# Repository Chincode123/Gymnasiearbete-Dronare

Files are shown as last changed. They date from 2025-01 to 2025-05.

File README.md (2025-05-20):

# Remote Controlled Drone

This repository contains the software part of a multi-person project with the goal of creating a remote-controlled drone using Arduino microcontrollers, basic, consumer components, and 3D printers.

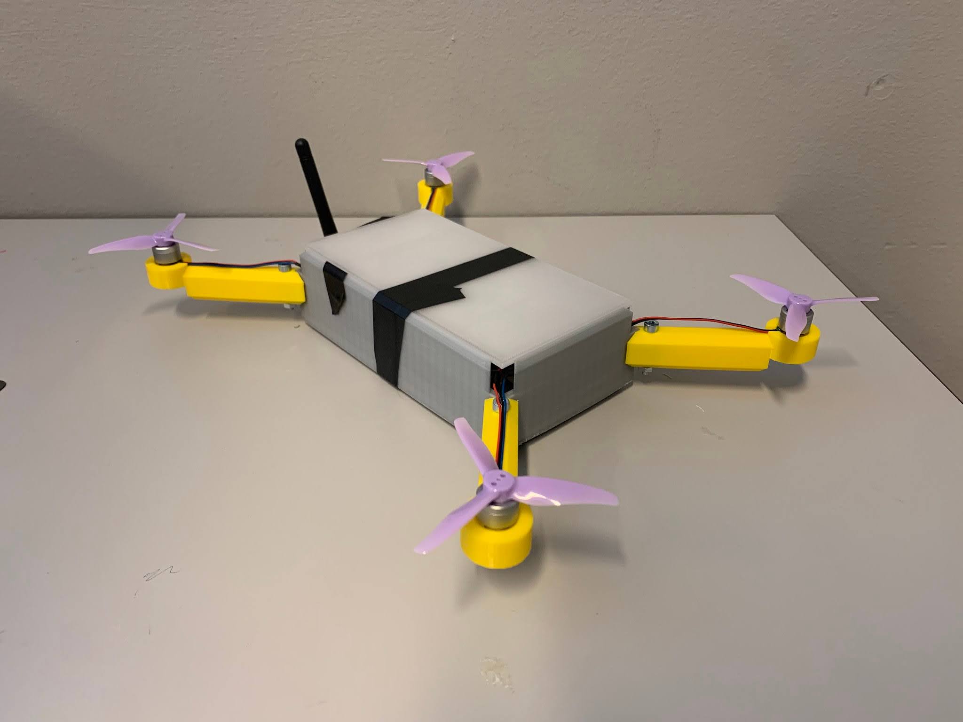
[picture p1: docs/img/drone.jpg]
Drone


## Table of Contents

- [Remote Controlled Drone](#remote-controlled-drone)
  - [Table of Contents](#table-of-contents)
  - [Project Abstract](#project-abstract)
  - [Materials](#materials)
  - [Drone](#drone)
    - [Basic Structure](#basic-structure)
      - [Setup](#setup)
      - [Main Loop](#main-loop)
        - [Radio Input](#radio-input)
        - [Flight Control](#flight-control)
        - [Radio Output](#radio-output)
      - [Important Helper Functions](#important-helper-functions)
        - [`setDeltaTime`](#setdeltatime)
        - [`sendRadio`](#sendradio)
        - [Activation and Deactivation Functions](#activation-and-deactivation-functions)
    - [Important Classes](#important-classes)
      - [`PID`](#pid)
      - [`MotorController`](#motorcontroller)
      - [`Orientation`](#orientation)
      - [`RadioSendStack`](#radiosendstack)
      - [`Timer` (drone)](#timer-drone)
      - [`vector3<T>`](#vector3t)
        - [Other](#other)
    - [Summary of Drone](#summary-of-drone)
  - [Receiver](#receiver)
    - [Basic Structure](#basic-structure-1)
      - [Setup](#setup-1)
      - [Main Loop](#main-loop-1)
        - [Serial Input](#serial-input)
        - [Radio Input](#radio-input-1)
    - [Important Classes](#important-classes-1)
      - [`InstructionHandler`](#instructionhandler)
      - [`Timer` (receiver)](#timer-receiver)
    - [Summary of Receiver](#summary-of-receiver)
  - [Control Panel](#control-panel)
    - [Basic Structure](#basic-structure-2)
      - [Setup](#setup-2)
      - [Main Loop](#main-loop-2)
        - [User Input](#user-input)
        - [Serial Communication](#serial-communication)
        - [Connection Status Indicators](#connection-status-indicators)
        - [Data Collection](#data-collection)
    - [Important Classes](#important-classes-2)
      - [`SerialMessage`](#serialmessage)
      - [`SerialReader`](#serialreader)
      - [`Terminal`](#terminal)
      - [`WritingHandler`](#writinghandler)
    - [Summary of Control Panel](#summary-of-control-panel)
  - [Simulation](#simulation)
    - [Features](#features)
    - [How to Use](#how-to-use)
    - [Notes](#notes)
    - [Summary of Simulation](#summary-of-simulation)
  - [Summary](#summary)

## Project-Abstract

The objective of this project was to explore the feasibility of designing and building a simple, radio-controlled drone using a 3D printer and an Arduino microcontroller. As the use of unmanned aerial vehicles (UAVs) becomes increasingly common in both civilian and military contexts, this project aimed to investigate how accessible such technology is for amateur hobbyists or small-scale operations. The drone was designed with a modular 3D-printed frame consisting of six parts: a central body, four arms, and a lid. The design process went through three major iterations, improving aspects such as size, weight, and internal component layout. The final version was longer and wider to better accommodate the electronic systems. The software was split into four modules: one for overall drone control, one for the radio receiver, a web-based interface for remote operation, and a Unity simulation to calibrate motor behavior using a PID controller. The finished drone had a total weight of approximately 453 grams and maintained wireless signal communication up to 290 meters, exceeding the 250-meter requirement. However, due to hardware limitations, flight testing was incomplete, and the drone's flight time could not be verified. Based on motor specifications, it is unlikely that the drone would meet the targeted 10-minute flight duration. Despite these limitations, the project successfully demonstrated the development of a modular frame, functional software integration, and RF24-based wireless communication. Future improvements should focus on optimizing aerodynamic design, enhancing sensor feedback integration, and developing efficient battery management. Overall, the project provides a strong foundation for future iterations and highlights both the possibilities and challenges of constructing UAVs with limited resources.

## Materials

- 4 DarwinFPV 1104 motors
- 4 Gemfan 3016 propellers
- 2 Ebyte E01-ML01DP5 radio tranceivers
- 1 MPU 6050 gyroscope/accelerometer
- 1 Capacitor
- 1 7.4 Volt 3000 mAh LiPo 2S battery
- 1 3.7 Volt 300 mAh LiPo 1S battery
- 1 Jhemcu EM-40A 4 in 1 ESC
- 1 Arduino MKR Zero
- 1 Arduino Uno
- 3D-printer + filament
- Soldering and wire handling equipment

## Drone

[`Drone.ino`](Drone/Drone.ino) is intended to be used with an `Arduino MKR Zero` alongside an [`MPU 6050`](https://www.invensense.com/products/motion-tracking/6-axis/mpu-6050/) gyroscope/accelerometer, an [`nRF24L01`](https://github.com/nRF24/RF24) radio device, and a set of `DarwinFPV 1104` brushless motors.

> **_NOTE:_** It will likely work with other components, with some minor modifications to the code.

### Basic Structure

[`Drone.ino`](Drone/Drone.ino) is the sketch file for the drone and, by using both public `Arduino` libraries and the custom-made [`DroneLibrary`](DroneLibrary), it handles the control flow for the drone.

> **_NOTE:_** To use `DroneLibrary` with the Arduino IDE, copy the `DroneLibrary` folder into your `Arduino/libraries` directory.

#### Setup

As with most `Arduino` sketches, the [`Drone.ino`](Drone/Drone.ino) file includes a setup function.

```cpp
void setup() {
    ...

    while (!radio.begin()) { }
    while (!configureRadio(radio)) { }
    radio.openWritingPipe(DRONE_ADDRESS);
    radio.openReadingPipe(1, RECEIVER_ADDRESS);
    radio.startListening();

    motorController.setTargetValues(&targetVelocity, &targetPitch, &targetRoll);
    motorController.setVelocityConstants(PID_Velocity);
    motorController.setPitchConstants(PID_Pitch);
    motorController.setRollConstants(PID_Roll);

    motorTL.attach(MOTOR_TL_Pin, 1000, 2000);
    motorTR.attach(MOTOR_TR_Pin, 1000, 2000);
    motorBR.attach(MOTOR_BR_Pin, 1000, 2000);
    motorBL.attach(MOTOR_BL_Pin, 1000, 2000);

    motorTL.writeMicroseconds(1000);
    motorTR.writeMicroseconds(1000);
    motorBR.writeMicroseconds(1000);
    motorBL.writeMicroseconds(1000);

    previousTime = micros();

    radioLogPush("Connected");

    ...
}
```

Firstly, the radio transceiver is configured:
- `radio.begin()` initializes the radio transceiver.
- `configureRadio(radio)` configures the transceiver's settings.
- Writing and reading pipes are opened with addresses defined in [`RadioData.h`](DroneLibrary/RadioData.h).
- `radio.startListening()` enables the transceiver to listen for instructions.

Secondly, the motor controller and motors are configured:
- The `MotorController` is set up with target values and PID constants.
- The motors are attached to their respective pins and initialized to their off position (1000 microseconds).

Lastly, the initial time is recorded, and a connection message is queued for transmission.

#### Main Loop

The main control flow is found within the `loop` function and can be divided into three sections: radio input, flight control, and radio output.

##### Radio Input

```cpp
void loop() {
    setDeltaTime();

    if (radio.available()) {
        radio.read(&messageIn, sizeof(messageIn));
        switch (messageIn.messageType) {
            case _MSG_CONTROLLER_INPUT:
                // code...
            case _MSG_ACTIVATE:
                // code...
            case _MSG_SET_PID_P:
                // code...
        }
    }

    ...
}
```

This part of the code checks for incoming radio messages and processes them based on their type. It handles controller input, activation/deactivation commands, PID updates, and target range updates.

##### Flight Control

```cpp
void loop() {
    ...

    if (activated) {
        orientation.update(deltaTime);
        motorController.calculatePower(orientation.velocity.z, orientation.angles.x, orientation.angles.y, deltaTime);

        motorTL.writeMicroseconds(map(motorPowerTL, -127, 127, 1000, 2000));
        motorTR.writeMicroseconds(map(motorPowerTR, -127, 127, 1000, 2000));
        motorBR.writeMicroseconds(map(motorPowerBR, -127, 127, 1000, 2000));
        motorBL.writeMicroseconds(map(motorPowerBL, -127, 127, 1000, 2000));
    } else {
        if (miscTimer.finished(1000)) {
            radioLogPush("Waiting for activation");
        } else {
            miscTimer.start(1000);
        }
    }

    ...
}
```
This part of the code updates the drone's sensor readings and calculates the required power for each motor if the drone is activated. 
- Firstly, the `update` method from the [Orientation](DroneLibrary/Orientation.h) class is called to collect and process data from the drone's gyroscope.
- Secondly, the new values are passed into the [`MotorController`](#motorcontroller) class' `calculatePower` method to calculate the optimal motor powers for the current moment.
- Lastly, a signal with the desired power is sent to each of the motors using `writeMicroseconds`.

If the drone isn't activated, it periodically sends a message to the controller which displays that it is connected and ready to be activated.

##### Radio Output

```cpp
void loop() {
    ...

    if (sending) {
        sending = !sendRadio();
    }

    sequenceTelemetry();

    ...
}
```

This part of the code handles outgoing radio messages. It sends queued messages and sequences telemetry data for transmission.

#### Important Helper Functions

##### `setDeltaTime`

```cpp
void setDeltaTime() {
    unsigned long currentTime = micros();
    if (currentTime < previousTime) {
        deltaTime = (float)(currentTime + (0xFFFFFFFF - previousTime)) / 1000000;
    } else {
        deltaTime = (float)(currentTime - previousTime) / 1000000;
    }
    previousTime = currentTime;
    if (deltaTime == 0) {
        deltaTime = 0.000001;
    }
}
```

Calculates the time delta between the current and previous loop iterations.

##### `sendRadio`

```cpp
bool sendRadio() {
    if (sendStack.getCount() <= 0) return true;

    radio.stopListening();
    RadioMessage message = sendStack.pop();
    bool result = radio.write(&message, sizeof(message));
    if (!result) {
        sendStack.push(message);
    }
    radio.startListening();
    return result;
}
```

Sends queued radio messages and retries if a message fails to send.

##### Activation and Deactivation Functions

```cpp
void activate() {
    if (activated) return;
    activated = true;
    orientation.begin(500);
    uint16_t power = 1000;
    float time = 0;
    while (time < 1) {
        setDeltaTime();
        motorTL.writeMicroseconds(power);
        motorTR.writeMicroseconds(power);
        motorBR.writeMicroseconds(power);
        motorBL.writeMicroseconds(power);
        time += deltaTime;
        power = 1000 + (time * 500);
  }
    radioLogPush("Activation complete");
}

void deactivate() {
  if (!activated) return;
  activated = false;
  orientation.end();
  uint16_t power = 1500;
  float time = 0;
  while (time < 1) {
      setDeltaTime();
      motorTL.writeMicroseconds(power);
      motorTR.writeMicroseconds(power);
      motorBR.writeMicroseconds(power);
      motorBL.writeMicroseconds(power);
      time += deltaTime;
      power = 1500 - (time * 500);
  }
  motorTL.writeMicroseconds(1000);
  motorTR.writeMicroseconds(1000);
  motorBR.writeMicroseconds(1000);
  motorBL.writeMicroseconds(1000);
}
```

The activation and deactivation functions start by calling the begin and end methods on the [`Orientation`](DroneLibrary/Orientation.h) class respectively, and set an activation flag to be either true or false respectively. After, they proceed to either ramp up or down the motors to or from 50% respectively. They end by queuing a message to be sent by radio, informing the user that the drone is either activated or deactivated. Additionally, the deactivation function also ensures that all the motor pins are turned off completely.

### Important Classes

For the drone to function properly, multiple classes were created to handle critical tasks.

#### `PID`

The [`PID`](DroneLibrary/PIDController.h) class implements a standard PID controller with a scalar value for each of the current **proportional** error, the cumulative **integral** of the error, and the current **derivative** of the error.

**To use the class:**
1. First, create an object. 
   ```cpp
    PID pid;
   ```
2. Then, use the `setConstants` method to set the PID constants. You can either:
   - Pass pointers to the scalar values:
     ```cpp
     float p = ..., i = ..., d = ...;
     pid.setConstants(&p, &i, &d);
     ```
   - Or pass a `PID_Instructions` struct:
     ```cpp
     PID_Instructions pidValues = {1.0, 0.5, 0.1};
     pid.setConstants(pidValues);
     ```
3. Use the `setTarget` method to set a pointer to the PID controller's target value.
   ```cpp
   float target = ...;
   pid.setTarget(&target);
   ```
4. Lastly, to acquire the controller's output, use the `calculate` method.
   ```cpp
   float output = pid.calculate(inputValue, deltaTime);
   ```

#### `MotorController`

The [`MotorController`](DroneLibrary/MotorController.h) class combines multiple [`PID`](#pid) controllers to handle the pitch, roll, and vertical velocity of the drone.

**To use the class:**
1. First, create an object by passing references to the motor power variables.
   ```cpp
    int8_t motorPowerTL, motorPowerTR, motorPowerBR, motorPowerBL;
    MotorController motorController(motorPowerTL, motorPowerTR, motorPowerBR, motorPowerBL);
   ```
2. Then, use the `setTargetValues` method to set pointers to the target values for velocity, pitch, and roll.
   ```cpp
    float targetVelocity = ..., targetPitch = ..., targetRoll = ...;
    motorController.setTargetValues(&targetVelocity, &targetPitch, &targetRoll);
   ```
3. Use the `setVelocityConstants`, `setPitchConstants`, and `setRollConstants` methods to set the PID constants for each respective controller.
   ```cpp
    PID_Instructions velocityConstants = ..., pitchConstants = ..., rollConstants = ...;
    motorController.setVelocityConstants(velocityConstants);
    motorController.setPitchConstants(pitchConstants);
    motorController.setRollConstants(rollConstants);
   ```
4. Lastly, to calculate the motor power values, use the `calculatePower` method by passing the current velocity, pitch, roll, and delta time.
   ```cpp
    motorController.calculatePower(currentVelocity, currentPitch, currentRoll, deltaTime);
   ```

#### `Orientation`

The [`Orientation`](DroneLibrary/Orientation.h) class is used to collect data from a connected [`MPU60X0`](https://www.invensense.com/products/motion-tracking/6-axis/mpu-6050/) gyroscope-accelerometer and process it into usable acceleration, velocity, and Euler-angle vectors.

**To use the class:**
1. First, create an object.
   ```cpp
   Orientation orientation(MPUAddress, positionOffset);
   ```
   - `MPUAddress`: The I2C address of the MPU.
   - `positionOffset`: The sensor's offset from the center of gravity.

2. **Initialize the MPU:**
   ```cpp
   orientation.begin();
   ```
   - Optionally, pass the number of cycles for offset calculation:
     ```cpp
     orientation.begin(500);
     ```

3. **Update orientation data:**
   ```cpp
   orientation.update(deltaTime);
   ```

4. **Access processed data:**
   - `rawAngularVelocity`: Raw angular velocity from the gyroscope (**°/s**).
   - `angles`: Euler angles (**°**).
   - `rawAcceleration`: Raw acceleration from the accelerometer (**m/s²**).
   - `acceleration`: Corrected acceleration at the center of gravity (**m/s²**).
   - `adjustedAcceleration`: Acceleration adjusted to the world frame (**m/s²**).
   - `velocity`: Velocity calculated from the adjusted acceleration (**m/s**).

5. **End the session:**
   ```cpp
   orientation.end();
   ```

The `Orientation` class provides robust tools for processing sensor data, making it ideal for applications requiring precise motion tracking and orientation correction.

#### `RadioSendStack`

The [`RadioSendStack`](DroneLibrary/RadioSendStack.h) class is used to handle a list of messages to be sent by radio and does this by implementing a linked list structure.

**To use the class:**
1. First, create an object.
   ```cpp
    RadioSendStack sendStack;
   ```
2. Then, use the `push` or `queue` methods to add a new message to the front or back of the list, respectively.
   ```cpp
    RadioMessage message = ...;
    sendStack.push(message);
    // or
    sendStack.queue(message);
   ```
3. Use the `peek` and `pop` methods to retrieve messages from the list:
   - `peek` retrieves a message without removing it. It can be used without arguments to retrieve the first element or with an index to retrieve a specific element.
     ```cpp
     RadioMessage message = sendStack.peek();
     ```
   - `pop` retrieves and removes a message from the list. It can be used without arguments to collect the first element or with an index to collect a specific element.
     ```cpp
     RadioMessage message = sendStack.pop();
     ```
4. Use the `getCount` method to retrieve the total number of messages in the list.
   ```cpp
    uint8_t count = sendStack.getCount();
   ```
5. Use the `clear` method to remove all elements from the list.
   ```cpp
    sendStack.clear();
   ```

#### `Timer` (drone)

The [`Timer`](DroneLibrary/Timer.h) class is a utility for managing timed events. It allows you to start, stop, and check if a timer has finished. It is particularly useful for scheduling periodic tasks or delays.

**To use the class:**
1. Create a `Timer` object.
   ```cpp
   Timer timer;
   ```
2. Use the `start` method to initialize the timer with a duration (in milliseconds).
   ```cpp
   timer.start(1000); // 1 second
   ```
3. Use the `finished` method to check if the timer has completed.
   ```cpp
   if (timer.finished()) {
       // Timer has finished
   }
   ```
4. Optionally, use the overloaded `finished` method to restart the timer with a new duration if it has finished.
   ```cpp
   if (timer.finished(500)) {
       // Timer has finished and restarted with a 500ms duration
   }
   ```
5. Use the `stop` method to reset the timer.
   ```cpp
   timer.stop();
   ```

#### `vector3<T>`

The [`vector3<T>`](DroneLibrary/Vectors.h) struct is a 3-dimensional vector template for simplifying vector calculations in tasks like physics simulations and orientation tracking.

**Features:**
- **Basic Operations**: Addition, subtraction, scalar multiplication, and division.
- **Dot Product**: Calculates the scalar product of two vectors.
- **Cross Product**: Calculates the vector product of two vectors.
- **Magnitude**: Computes the vector's length.
- **Projection**: Projects one vector onto another.

**To use the class:**
1. Create a vector:
   ```cpp
   vector3<float> v1 = {1.0, 2.0, 3.0};
   ```
2. Perform operations:
   ```cpp
   vector3<float> sum = v1 + v2; // Addition
   float dot = v1 * v2;          // Dot product
   vector3<float> cross = crossProduct(v1, v2); // Cross product
   ```

**Public Members:**
- `T x, y, z`: The vector components.

**Public Methods:**
- `float magnitude()`: Returns the vector's length.

The `vector3<T>` struct is a versatile tool for 3D vector calculations, ideal for physics, robotics, and drone orientation systems.

##### Other

There are also a few structs defined in [`RadioData.h`](DroneLibrary/RadioData.h) to simplify data handling:

- `ControllerInstructions` for handling controller input
```cpp
struct ControllerInstructions {
    int8_t x;
    int8_t y;
    int8_t power;
};
```

- `PID_Instructions` for handling PID settings
```cpp
struct PID_Instructions {
    float k_p, k_i, k_d;
};
```

- `TargetRangeInstructions` for handling the different ranges that the drone's target values can reside in
```cpp
struct TargetRangeInstructions {
    float pitchMax, rollMax, verticalVelocityMax;
};
```

- `RadioMessage` for storing a message to be sent by radio with its associated `messageType`
```cpp
struct RadioMessage {
    uint8_t messageType;
    uint8_t dataBuffer[31];
};
```

### Summary of [Drone](#drone)

The `Drone.ino` sketch is designed for an Arduino MKR Zero and integrates with various components like the [`MPU 6050`](https://www.invensense.com/products/motion-tracking/6-axis/mpu-6050/), [`nRF24L01`](https://github.com/nRF24/RF24) radio device, and DarwinFPV 1104 brushless motors. The setup function initializes the radio transceiver and motor configurations, while the main loop handles radio input, flight control, and radio output. Important helper functions include `setDeltaTime` for time calculations and `sendRadio` for managing radio communications. The drone's functionality is supported by several key classes such as `PID`, `MotorController`, `Orientation`, and `RadioSendStack`, which manage tasks like PID control, motor power calculations, orientation data processing, and radio message handling. Custom data types like `vector3<T>` are also used to facilitate data management.

## Receiver

[`Receiver.ino`](Receiver/Receiver.ino) is intended to be used with an `Arduino UNO` alongside an [`nRF24L01`](https://github.com/nRF24/RF24) radio device, connected by USB to a computer that is running the [`Control Panel`](#control-panel) program.

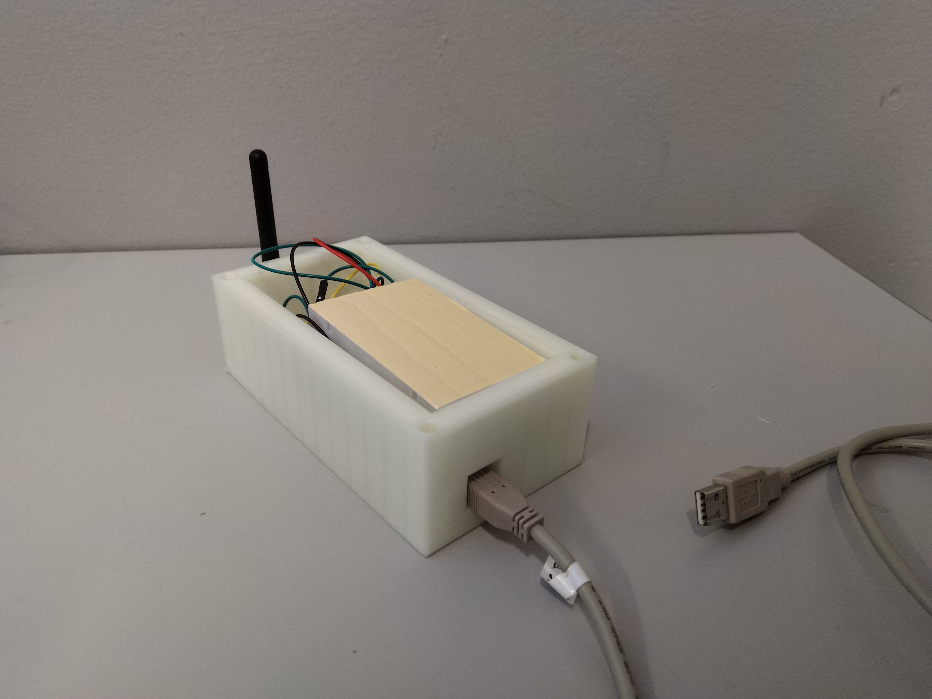
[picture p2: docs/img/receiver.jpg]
Receiver


### Basic Structure

[`Receiver.ino`](Receiver/Receiver.ino) is the sketch file for the receiver and, by using both public `Arduino` libraries and the custom-made [`DroneLibrary`](DroneLibrary), it handles the control flow for relaying messages between the drone and the controller.

#### Setup

As with most `Arduino` sketches, the [`Receiver.ino`](Receiver/Receiver.ino) file includes a setup function.

```cpp
void setup() {
    ...

    Serial.begin(115200);
    while (!Serial);

    if (!radio.begin()) {
        Serial.println(F("Radio hardware not responding!"));
        while (true);
    }
    if (!configureRadio(radio)) {
        Serial.println("Radio configuration failed");
        while (true);
    }
    radio.openWritingPipe(RECEIVER_ADDRESS);
    radio.openReadingPipe(1, DRONE_ADDRESS);
    radio.startListening();

    previousTime = micros();

    ...
}
```

Firstly, Serial is configured with a baud rate of `115200`.  
Secondly, the radio transceiver is configured:
- `radio.begin()` initializes the radio transceiver.
- `configureRadio(radio)` configures the transceiver's settings.
- Writing and reading pipes are opened with addresses defined in [`RadioData.h`](DroneLibrary/RadioData.h).
- `radio.startListening()` enables the transceiver to listen for instructions.

Lastly, the initial time is recorded.

> **_NOTE:_** The transceiver's initialization and configuration are placed in while loops to prevent the program from proceeding if any part fails.

#### Main Loop

The main control flow is found within the `loop` function and can be divided into two sections: serial input and radio input.

##### Serial Input

```cpp
void loop() {
    ...

    if (instructionHandler.read()) {
        uint8_t messageType = instructionHandler.getData(readBuffer);
        messageOut.messageType = messageType;
        memcpy(messageOut.dataBuffer, readBuffer, sizeof(messageOut.dataBuffer));

        bool result = false;
        if (sending) 
            result = send();
        if (result) {
            sending = false;
            instructionHandler.acknowledge(messageType);
        }

        ...
    }

    ...
}
```

This part of the code checks for incoming serial messages from the controller using the [`InstructionHandler`](#instructionhandler) class. If a message is received, it processes the message, sends it to the drone via the radio, and acknowledges the message if the transmission is successful.

##### Radio Input

```cpp
void loop() {
    ...

    if (radio.available()) {
        sending = true;

        connectionStatus = connectionStatus | 0b010;

        radio.read(&messageIn, sizeof(messageIn));

        switch (messageIn.messageType) {
            case _MSG_DRONE_LOG:
                dronePrint((const char*)messageIn.dataBuffer);
                break;
            case _MSG_ACTIVATE:
                connectionStatus = connectionStatus | 0b100;
                break;
            case _MSG_DEACTIVATE:
                break;
            default:
                instructionHandler.write(messageIn.dataBuffer, messageIn.messageType);
                break;
        }
    }

    instructionHandler.write(&connectionStatus, _MSG_CONNECTION_STATUS);
    instructionHandler.write((uint8_t*)&deltaTime, _MSG_RECEIVER_DELTATIME);

    ...
}
```

This part of the code checks for incoming radio messages from the drone. If a message is received, it processes the message based on its type and forwards it to the controller via the serial connection. It also updates the connection status and delta time.

### Important Classes

#### `InstructionHandler`

The [`InstructionHandler`](DroneLibrary/InstructionHandler.h) class is used to manage serial communication between the receiver and the controller. It handles reading, writing, and acknowledging messages.

**To use the class:**
1. Create an object.
   ```cpp
   InstructionHandler instructionHandler;
   ```
2. Use the `read` method to check if a new message has been received via serial.
   ```cpp
   if (instructionHandler.read()) {
       // Process the message
   }
   ```
3. Use the `getData` method to retrieve the message data and type.
   ```cpp
   uint8_t messageType = instructionHandler.getData(buffer);
   ```
4. Use the `write` method to send a message via serial.
   ```cpp
   instructionHandler.write(data, messageType);
   ```
5. Use the `acknowledge` method to send an acknowledgment for a received message.
   ```cpp
   instructionHandler.acknowledge(messageType);
   ```

#### `Timer` (receiver)

See [`Timer`](#timer-drone).

### Summary of [Receiver](#receiver)

The `Receiver.ino` sketch acts as a bridge between the drone and the controller. It uses an [`nRF24L01`](https://github.com/nRF24/RF24) radio device to communicate with the drone and a serial connection (115200 baud) to communicate with the controller. The sketch relies on the `InstructionHandler` class to manage serial communication and ensures that messages are properly relayed between the two systems. The setup function initializes the radio transceiver and serial communication, while the main loop handles serial input, radio communication, and message forwarding. The receiver monitors connection status for both the drone and its activation state and uses timer-based message handling to improve communication reliability. Additionally, it ensures acknowledgment of serial messages and processes drone logs for better debugging and monitoring.

## Control Panel

The `Control Panel` is a web-based application designed to interact with the drone via the [`Receiver`](#receiver). It provides a graphical interface for controlling the drone, adjusting PID values, and monitoring telemetry data.

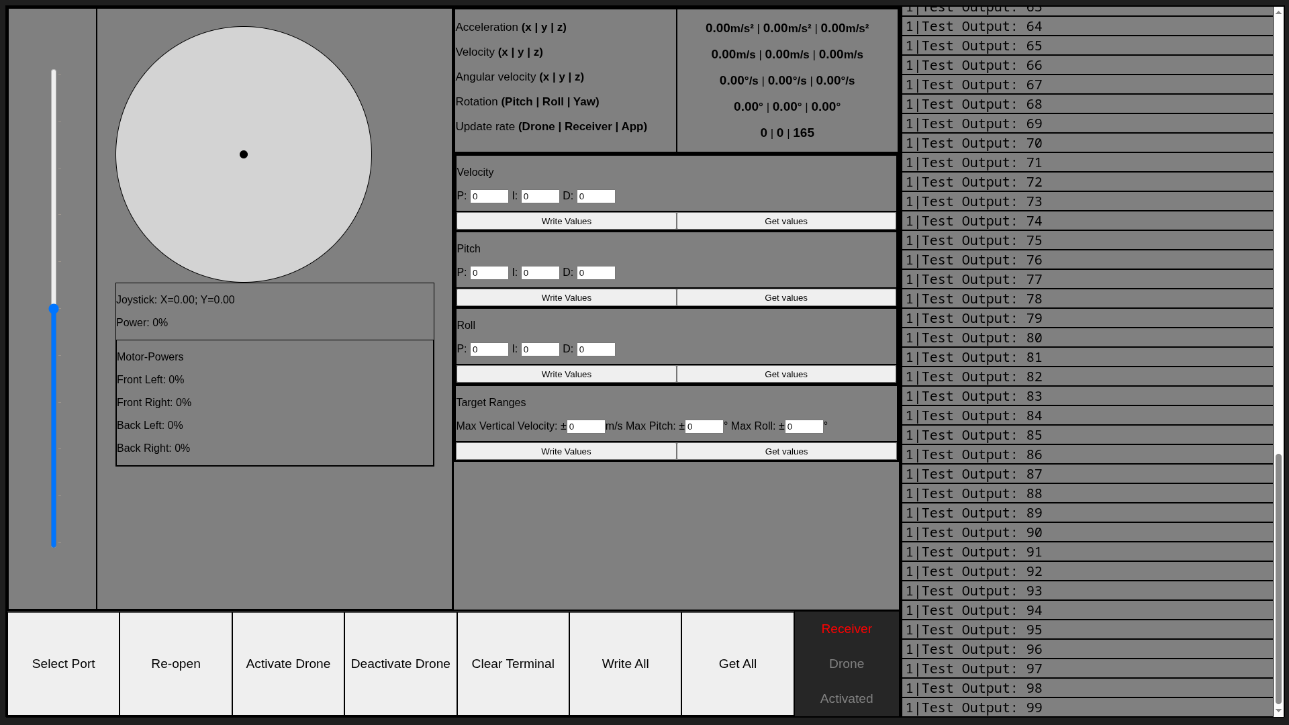
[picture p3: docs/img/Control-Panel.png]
Control Panel


### Basic Structure

The `Control Panel` application is built using HTML, CSS, and JavaScript. It handles the control flow for interacting with the drone and receiver by using both browser APIs and custom JavaScript classes.

#### Setup

The setup process involves initializing the serial connection and setting up event listeners for user interactions:
- A button allows the user to select a serial port using the browser's Web Serial API.
- Once a port is selected, it is opened with predefined settings.
- Periodic read and write operations are scheduled to handle communication with the receiver.
- A message is logged to the terminal upon successful connection.

#### Main Loop

The main control flow is divided into two sections: user input and serial communication.

##### User Input

- Handles keyboard input for controlling the joystick and power levels.
- Updates the joystick position and power level based on user input.
- Supports additional input methods such as mouse and gamepad for controlling the drone.

##### Serial Communication

- Sends instructions to the receiver via the serial port.
- Uses a dedicated class to manage outgoing messages and ensure proper communication flow.

##### Connection Status Indicators

The `Control Panel` displays the connection status of the receiver, drone, and drone activation state using color-coded indicators:

  - <span style="color:green;">connected</span>
  - <span style="color:red;">disconnected</span>
  - <span style="color:grey;">unkown</span>

These indicators update dynamically based on received messages and reset to disconnected/unkown if no updates are received within a timeout period.

##### Data Collection

The `Control Panel` application includes functionality for collecting flight data during the drone's operation. This data is periodically gathered and saved in a structured format for analysis. The data includes information such as time, acceleration, velocity, angular velocity, rotation, controller power, joystick position, FPS, and motor powers.

Once data collection stops, the collected data is saved as a `JSON` file with a timestamped filename in the `FlightData` folder.

For a detailed explanation of the flight data format and structure, refer to the [Flight Data README](FlightData/README.md).

This feature allows users to analyze the drone's performance and behavior during flights.

### Important Classes

For the `Control Panel` to function properly, multiple classes were created to handle critical tasks.

#### `SerialMessage`

The `SerialMessage` class defines the structure of messages exchanged between the `Control Panel` and the `Receiver`.

**To use the class:**
1. First, create an object.
   ```javascript
   const message = new SerialMessage();
   ```
2. Use the `set` method to initialize a message with a specific type.
   ```javascript
   message.set(type);
   ```
3. Use the `reset` method to reset the message state.
   ```javascript
   message.reset();
   ```

#### `SerialReader`

The `SerialReader` class handles reading and parsing incoming serial data.

**To use the class:**
1. First, create an object.
   ```javascript
   const reader = new SerialReader();
   ```
2. Use the `read` method to process incoming bytes.
   ```javascript
   const result = reader.read(byte);
   ```
   - **Structure of `result`:**
     - `done` (boolean): Indicates whether a complete message has been read.
     - `reading` (boolean): Indicates whether the reader is currently processing a message.
     - `data` (Uint8Array): Contains the raw data of the message (only available when `done` is `true`).
     - `messageType` (number): The numeric type of the message (only available when `done` is `true`).
     - `messageTypeName` (string): The name of the message type (only available when `done` is `true`).

     Example:
     ```javascript
     const result = serialReader.read(byte);
     if (result.done) {
         console.log(result.messageTypeName); // e.g., "pid-velocity"
         console.log(result.data); // Uint8Array containing the message data
     }
     ```
3. Use specialized methods to parse specific data types:
   - `readPIDInstruction(data)`
   - `readTargetRanges(data)`
   - `readVector(data)`
   - `readDeltaTime(data)`
   - `readMotorPowers(data)`

#### `Terminal`

The `Terminal` class manages the display of logs and messages in the terminal section of the interface.

**To use the class:**
1. First, create an object.
   ```javascript
   const terminal = new Terminal();
   ```
2. Use the `addToTerminal` method to add a log entry.
   ```javascript
   terminal.addToTerminal(log);
   ```
3. Use the `clear` method to clear the terminal.
   ```javascript
   terminal.clear();
   ```

#### `WritingHandler`

The `WritingHandler` class manages outgoing instructions to the `Receiver`.

**To use the class:**
1. First, create an object.
   ```javascript
   const handler = new WritingHandler();
   ```
2. Use the `set` or `setWithConfirm` method to set the current instructions and type.
   ```javascript
   handler.set(instructions, type);
   handler.setWithConfirm(instructions, type, value);
   ```
   - **Details:**
     - `set`: Sets the current instructions and their type. Marks the handler as having instructions to send.
       Example:
       ```javascript
       const instructions = getControllerInstructions(joystick.x, joystick.y, power);
       writingHandler.set(instructions, SerialMessage.messageTypeFromName.get("controller-instructions"));
       ```
     - `setWithConfirm`: Similar to `set`, but also sets a confirmation value to ensure the data is acknowledged before proceeding. Used when the data requires confirmation from the receiver.
       Example:
       ```javascript
       const pidValues = { p: 1.0, i: 0.5, d: 0.1 };
       const instructions = getPIDInstructions(pidValues, "velocity");
       writingHandler.setWithConfirm(instructions, SerialMessage.messageTypeFromName.get("pid-velocity"), pidValues);
       ```
3. Use the `get` method to retrieve the current instructions if available.
   ```javascript
   const instructions = handler.get();
   ```
   - **Details:**
     - Retrieves the current instructions if available.
     - If no instructions are set, it defaults to sending controller instructions.
     - Example:
       ```javascript
       const instructions = writingHandler.get();
       ```
4. Use the `acceptAcknowledge` method to handle acknowledgment messages.
   ```javascript
   handler.acceptAcknowledge(messageType);
   ```
   - **Details:**
     - Handles acknowledgment messages from the receiver.
     - If the acknowledgment matches the current instructions type, it clears the current instructions.
     - Example:
       ```javascript
       writingHandler.acceptAcknowledge(SerialMessage.messageTypeFromName.get("pid-velocity"));
       ```

### Summary of [Control Panel](#control-panel)

The `Control Panel` application provides an intuitive interface for controlling the drone and monitoring its telemetry. It uses the `SerialMessage`, `SerialReader`, `Terminal`, and `WritingHandler` classes to manage communication with the `Receiver`. The application supports joystick, keyboard, and gamepad inputs for controlling the drone and allows real-time adjustments to PID constants and target ranges. The `WritingHandler` class ensures proper acknowledgment of instructions sent to the receiver, improving communication reliability. Additionally, the application collects and saves flight data for post-flight analysis, enabling users to evaluate the drone's performance and behavior during flights.

## Simulation

The simulation is a Unity-based project designed to calibrate the PID settings for the drone. It provides a virtual environment where the drone's behavior can be tested and adjusted without requiring physical hardware. The simulation is intended to be run in the Unity editor, as the PID values and other settings can only be updated through the Inspector.

### Features

- **PID Calibration**: Adjust the proportional, integral, and derivative constants for pitch, roll, and velocity in real-time.
- **Propeller Visualization**: Displays the forces applied by each propeller using Gizmos for better understanding of the drone's behavior.
- **Center of Mass Adjustment**: Allows visualization and adjustment of the drone's center of mass to observe its impact on stability.
- **Velocity and Orientation Feedback**: Provides visual feedback on the drone's velocity and orientation using Gizmos.

### How to Use

1. Open the Unity project located in the `Simulation/ga-drone-simulation` folder.
2. Select the GameObject in the scene with the `DroneController` component.
3. Use the Inspector to adjust the PID constants (`P`, `I`, `D`) for pitch, roll, and velocity, and the drones mass and center of mass.
4. Play the scene in the Unity editor to observe the drone's behavior.
5. Use the keyboard or a game controller to provide input:
   - **Throttle**: `Left Shift` or `Left Trigger` to decrease, and `Space` or `Right Trigger` to increase.
   - **Pitch**: `W` (forward) and `S` (backward).
   - **Roll**: `A` (left) and `D` (right).
6. Observe the drone's response and adjust the PID values as needed to achieve stable flight.

### Notes

- The simulation uses a custom `DroneController` script to emulate the drone's physics and control logic.
- The `CameraController` script ensures the camera smoothly follows the drone for better visualization.
- The simulation is not a replacement for real-world testing but serves as a tool to approximate and refine PID settings before applying them to the physical drone.

### Summary of Simulation

The simulation provides a virtual environment for testing and calibrating the drone's PID settings. It allows users to adjust parameters like proportional, integral, and derivative constants, as well as the drone's mass and center of mass, in real-time. By visualizing propeller forces, velocity, and orientation, users can refine the drone's stability and behavior before applying changes to the physical hardware. While not a substitute for real-world testing, the simulation serves as a valuable tool for approximating and optimizing flight performance.

## Summary

This project involves the development of a remote-controlled drone using Arduino microcontrollers, basic components, and 3D-printed parts. The software is divided into four main components:

1. **Drone**: The core flight system, implemented on an Arduino MKR Zero, integrates sensors like the MPU 6050 and nRF24L01 radio for communication. It uses custom classes for PID control, motor management, and orientation tracking to ensure stable flight.

2. **Receiver**: Acts as a bridge between the drone and the control panel, using an Arduino UNO and nRF24L01 radio to relay messages. It manages serial communication with the control panel and radio communication with the drone.

3. **Control Panel**: A web-based application that provides an interface for controlling the drone, adjusting PID values, and monitoring telemetry. It supports multiple input methods and includes features for data collection and analysis.

4. **Simulation**: A Unity-based virtual environment for testing and calibrating PID settings. It allows users to visualize and refine the drone's behavior before applying changes to the physical hardware.

The project emphasizes modularity, with reusable classes and data structures, and provides tools for both real-world and simulated testing to optimize drone performance.

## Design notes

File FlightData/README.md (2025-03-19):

# Flight Data

This folder acts as a potential location for the data from the drone's flights. The data from each of the flights are saved as separate `JSON`-files.

## Flight Data Format

Each flight data file contains the following structure:

- `startDateTime`: The start time of the flight data collection (ISO 8601 format).
- `endDateTime`: The end time of the flight data collection (ISO 8601 format).
- `data`: An array of data points collected during the flight. Each data point includes:
  - `time`: The elapsed time in seconds since the start of the flight.
  - `acceleration`: The acceleration values along the x, y, and z axes (in m/s²):
    - `x`: Acceleration along the x-axis.
    - `y`: Acceleration along the y-axis.
    - `z`: Acceleration along the z-axis.
  - `velocity`: The velocity values along the x, y, and z axes (in m/s):
    - `x`: Velocity along the x-axis.
    - `y`: Velocity along the y-axis.
    - `z`: Velocity along the z-axis.
  - `angularVelocity`: The angular velocity values along the x, y, and z axes (in degrees per second):
    - `x`: Angular velocity around the x-axis.
    - `y`: Angular velocity around the y-axis.
    - `z`: Angular velocity around the z-axis.
  - `rotation`: The rotation values (in degrees):
    - `pitch`: Rotation around the x-axis.
    - `roll`: Rotation around the y-axis.
    - `yaw`: Rotation around the z-axis.
  - `controllerPower`: The user-inputted power value (as a percentage).
  - `joystick`: The joystick position values along the x and y axes (normalized between -1 and 1). The combined magnitude of `x` and `y` is always less than or equal to 1:
    - `x`: Joystick position along the x-axis.
    - `y`: Joystick position along the y-axis.
  - `fps`: The frames-per-second values for different components:
    - `app`: The application update rate.
    - `drone`: The drone update rate.
    - `receiver`: The receiver update rate.
  - `motorPowers`: The motor power values for each motor as a percentage between 0% and 100%:
    - `frontLeft`: The power of the front-left motor.
    - `frontRight`: The power of the front-right motor.
    - `backLeft`: The power of the back-left motor.
    - `backRight`: The power of the back-right motor.

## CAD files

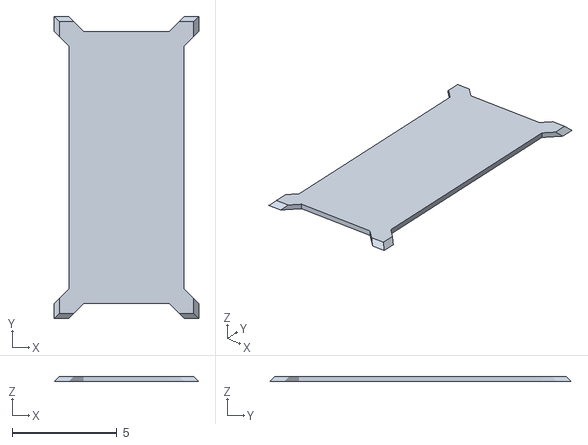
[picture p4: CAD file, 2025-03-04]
Simulation/ga-drone-simulation/Assets/model/Lock.obj
6.91 x 14.4 x 0.25

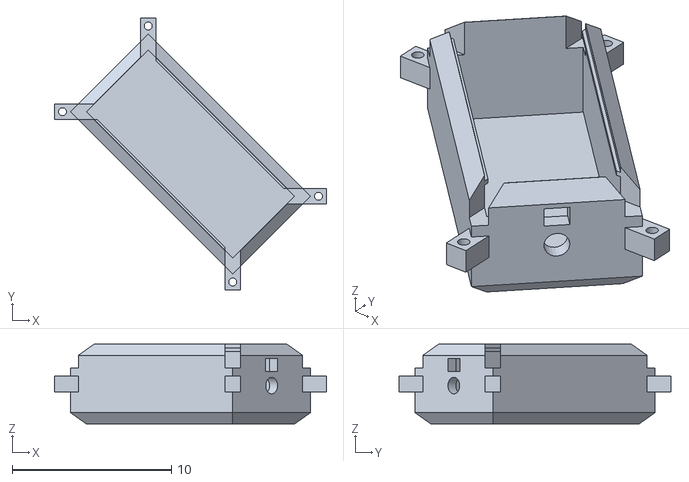
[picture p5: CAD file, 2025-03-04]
Simulation/ga-drone-simulation/Assets/model/vFINAL_kropp.obj
17.1 x 17.1 x 5.00

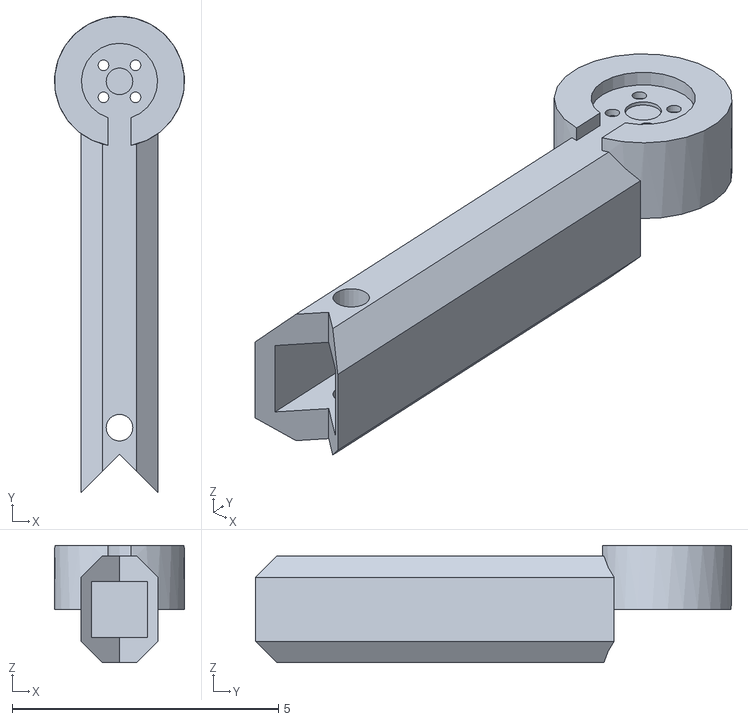
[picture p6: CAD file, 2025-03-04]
Simulation/ga-drone-simulation/Assets/model/arm.obj
2.44 x 8.94 x 2.20

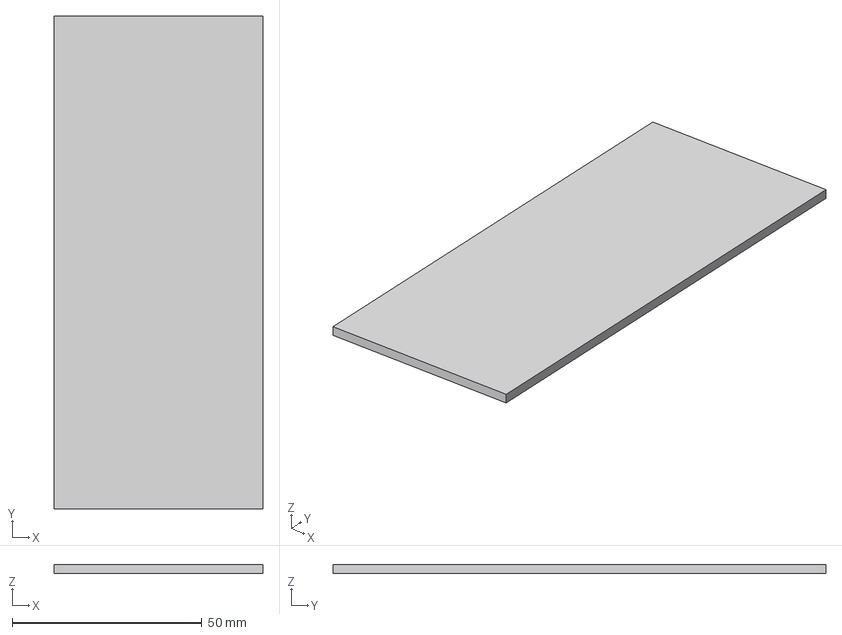
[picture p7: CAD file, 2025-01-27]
Simulation/ga-drone-simulation/Assets/model/Lock v1.3mf
55.0 x 130.0 x 2.50 mm

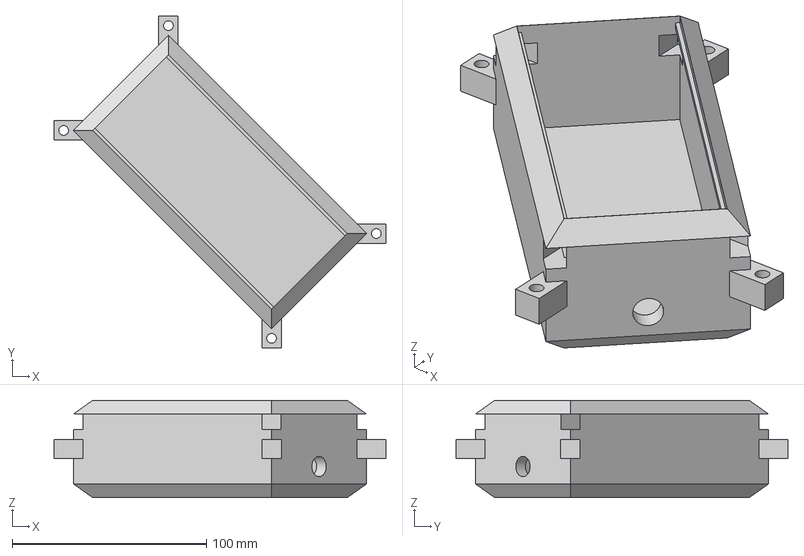
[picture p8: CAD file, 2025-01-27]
Simulation/ga-drone-simulation/Assets/model/kropp.3mf
170.8 x 170.8 x 50.0 mm

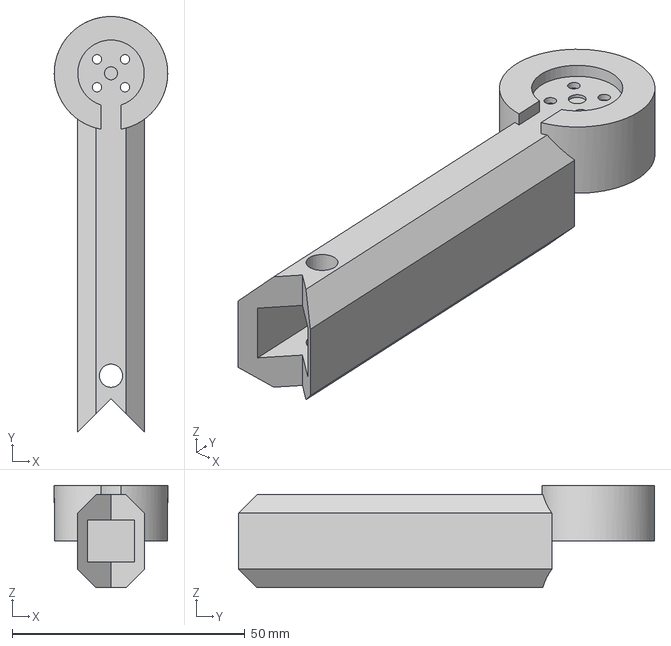
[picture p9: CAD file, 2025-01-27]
Simulation/ga-drone-simulation/Assets/model/armv3.3mf
24.4 x 89.4 x 22.0 mm

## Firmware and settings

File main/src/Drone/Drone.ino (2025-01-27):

#include <SPI.h>
#include <nRF24L01.h>
#include <RF24.h>
#include "../utils/RadioData.h"
#include "../utils/MotorControl.h"
#include "../utils/Vectors.h"
#include "../utils/Orientation.h"
#include "../utils/RadioSendStack.h"

#define CE_PIN 6
#define CSN_PIN 7

// Radio
RF24 radio(CE_PIN, CSN_PIN, 4000000);
uint8_t readBuffer[32];
RadioSendStack sendStack;


// Motors
#define MOTOR_TL_Pin 5
#define MOTOR_TR_Pin 4
#define MOTOR_BR_Pin 3
#define MOTOR_BL_Pin 2
uint8_t motorPowerTL, motorPowerTR, motorPowerBR, motorPowerBL;
MotorController motorController(motorPowerTL, motorPowerTR, motorPowerBR, motorPowerBL);


// PID-values
float targetVelocity;
float velocityP = 0; 
float velocityI = 0; 
float velocityD = 0;
float maxVelocity;

float targetPitch;
float pitchP = 0; 
float pitchI = 0; 
float pitchD = 0;
float maxPitch;

float targetRoll;
float rollP = 0; 
float rollI = 0; 
float rollD = 0;
float maxRoll;

PID_Instructions pidIn, pidOut;

// Delta time
unsigned long previousTime
float deltaTime;
void setDeltaTime();


// Spatial orientation/acceleration/velocity
Orientation orientation;


bool activated = false;


void setup() {
    // Set up radio
    while(!radio.begin());
    if(!configureRadio(radio)) {
        while (true);
    }
    radio.openWritingPipe(DRONE_ADDRESS);
    radio.openReadingPipe(1, RECEIVER_ADDRESS);

    // Set up motor controller
    motorController.setTargetValues(targetVelocity, targetPitch, targetRoll);
    motorController.setVelocityConstants(velocityP, velocityI, velocityD);
    motorController.setPitchConstants(pitchP, pitchI, pitchD);
    motorController.setRollConstants(rollP, rollI, rollD);

    pinMode(MOTOR_TL_Pin, OUTPUT);
    pinMode(MOTOR_TR_Pin, OUTPUT);
    pinMode(MOTOR_BR_Pin, OUTPUT);
    pinMode(MOTOR_BL_Pin, OUTPUT);
    
    // Initial time
    previousTime = millis();

    consoleLog("Connected", true);
}

void loop() {
    setDeltaTime();
    
    // Radio read
    if (radio.available()) {
        radio.read(&readBuffer, sizeof(readBuffer));

        RadioMessage messageIn, messageOut;
        memcpy(&messageIn, &readBuffer, sizeof(messageIn));

        switch (messageIn.type) {
            case _MSG_CONTROLLER_INPUT:
                controllerInstructions controller;
                memcpy(&controller, &messageIn.dataBuffer, sizeof(controller));
                
                targetVelocity = maxVelocity * (float)controller.power / 127;
                targetPitch = maxPitch * ((float)controller.stick_X / 127);
                targetRoll = maxRoll * ((float)controller.stick_Y / 127);
                break;
            case _MSG_ACTIVATE:
                if (activated) break;
                activated = true;

                orientation.begin(500);

                // Ramp up motors to 50%
                uint8_t power = 0;
                float time = 0;
                while (time < 1) {
                    setDeltaTime();
                    analogWrite(MOTOR_TL_Pin, power);
                    analogWrite(MOTOR_TR_Pin, power);
                    analogWrite(MOTOR_BR_Pin, power);
                    analogWrite(MOTOR_BL_Pin, power);

                    time += deltaTime;
                    power = 128 * time;
                }
                
                consoleLog("Activation complete", true);
                break;
            case _MSG_DEACTIVATE:
                if (!activated) break;
                activated = false;

                orientation.end();

                // Ramp down motors to 0%
                uint8_t power = 0;
                float time = 0;
                while (time < 1) {
                    setDeltaTime();
                    analogWrite(MOTOR_TL_Pin, power);
                    analogWrite(MOTOR_TR_Pin, power);
                    analogWrite(MOTOR_BR_Pin, power);
                    analogWrite(MOTOR_BL_Pin, power);

                    time += deltaTime;
                    power = 128 * (1 - time);
                }
                digitalWrite(MOTOR_TL_Pin, LOW);
                digitalWrite(MOTOR_TR_Pin, LOW);
                digitalWrite(MOTOR_BR_Pin, LOW);
                digitalWrite(MOTOR_BL_Pin, LOW);

                consoleLog("Deactivated");
                break;
            case _MSG_SET_PID_V:
                memcpy(&pidIn, &messageIn.dataBuffer, sizeof(pidIn));
                velocityP = pidIn.k_p;
                velocityI = pidIn.k_i;
                velocityD = pidIn.k_d;
                break;
            case _MSG_SET_PID_P:
                memcpy(&pidIN, &messageIn.dataBuffer, sizeof(pidIn));
                pitchP = pidIn.k_p;
                pitchI = pidIn.k_i;
                pitchD = pidIn.k_d;
                break;
            case _MSG_SET_PID_R:
                memcpy(&pidIn, &messageIn.dataBuffer, sizeof(pidIn));
                rollP = pidIn.k_p;
                rollI = pidIn.k_i;
                rollD = pidIn.k_d;
                break;
            case _MSG_REQUEST_PID_V:
                pidOut.k_p = velocityP;
                pidOut.k_i = velocityI;
                pidOut.k_d = velocityD;
                memcpy(&messageOut.dataBuffer, pidOut, sizeof(pidOut));
                sendStack.push(&messageOut, sizeof(messageOut));
                break;
            case _MSG_REQUEST_PID_P:
                pidOut.k_p = pitchP;
                pidOut.k_i = pitchI;
                pidOut.k_d = pitchD;
                memcpy(&messageOut.dataBuffer, pidOut, sizeof(pidOut));
                sendStack.push(&messageOut, sizeof(messageOut));
                break;
            case _MSG_REQUEST_PID_R:
                pidOut.k_p = rollP;
                pidOut.k_i = rollI;
                pidOut.k_d = rollD;
                memcpy(&messageOut.dataBuffer, pidOut, sizeof(pidOut));
                sendStack.push(&messageOut, sizeof(messageOut));
                break;
            case _MSG_SET_TARGET_RANGES:
                TargetRangeInstructions targetRanges;
                memcpy(&targetRanges, &messageIn.dataBuffer, sizeof(targetRanges));
                maxVelocity = targetRanges.verticalVelocityMax;
                maxPitch = targetRanges.pitchMax;
                maxRoll = targetRanges.rollMax;
                break;
            case _MSG_REQUEST_TARGET_RANGES:
                TargetRangeInstructions targetRanges = {maxPitch, maxRoll, maxVelocity};
                memcpy(&messageOut.dataBuffer, targetRanges, sizeof(targetRanges));
                sendStack.push(&messageOut, sizeof(messageOut));
                break;
            default:
                consoleLog("Error interpreting messageType", false);
                break;
        }
    }

    if (activated) {
        orientation.update(deltaTime);
        motorController.calculatePower(orientation.velocity.z, orientation.angles.x, orientation.angles.y, deltaTime);
        analogWrite(MOTOR_TL_Pin, motorPowerTL);   
        analogWrite(MOTOR_TR_Pin, motorPowerTR);   
        analogWrite(MOTOR_BR_Pin, motorPowerBR);   
        analogWrite(MOTOR_BL_Pin, motorPowerBL);
    }
    else {
        if (millis() % 5000 == 0) {
            consoleLog("Waiting for activation");
        }
    }

    // Output
    sendRadio();
}

void setDeltaTime() {
    unsigned long currentTime = millis();
    deltaTime = (float)(currentTime - previousTime) / 1000;
    previusTime = currentTime;
}

void sendRadio() {
    while (sendStack.count > 0 && !radio.available()) {
        radio.stopListening();
        radioStackElement* data = sendStack.pop();
        bool result = radio.write(data->value, data->size);
        radio.startListening();

        if (!result){
            sendStack.push(data->value, data->size);
            break;
        }
    }
}

void consoleLog(const char* message, bool important) {
    #define DRONE_LOG
    RadioMessage logMessage;
    logMessage.messageType = _MSG_DRONE_LOG;
    uint8_t messageLength = strlen(message);
    messageLength = (messageLength < 31) ? messageLength : 31;
    memcpy(&logMessage.dataBuffer, &message, messageLength);
    
    if (impotrant)
        sendStack.push(&logMessage, sizeof(logMessage));
    else
        sendStack.queue(&logMessage, sizeof(logMessage));
}

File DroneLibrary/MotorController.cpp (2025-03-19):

#include "MotorController.h"
#include <Arduino.h>

MotorController::MotorController(int8_t& motorPowerTL, int8_t& motorPowerTR, int8_t& motorPowerBR, int8_t& motorPowerBL)
 : motorPowerTL(motorPowerTL), motorPowerTR(motorPowerTR), motorPowerBR(motorPowerBR), motorPowerBL(motorPowerBL) {}

void MotorController::setTargetValues(float *targetVelocity, float *targetPitch, float *targetRoll) {
    velocityController.setTarget(targetVelocity);
    pitchController.setTarget(targetPitch);
    rollController.setTarget(targetRoll);
}

void MotorController::setVelocityConstants(const PID_Instructions &values) {
    velocityController.setConstants(values);
}

void MotorController::setPitchConstants(const PID_Instructions &values) {
    pitchController.setConstants(values);
}

void MotorController::setRollConstants(const PID_Instructions &values) {
    rollController.setConstants(values);
}

void MotorController::calculatePower(float velocity, float pitch, float roll, float deltaTime) {
    float basePower = velocityController.calculate(velocity, deltaTime);
    basePower = constrain(basePower, -127, 127);
    float pitchShift = pitchController.calculate(pitch, deltaTime);
    float rollShift = rollController.calculate(roll, deltaTime);

    motorPowerTL = int8_t(constrain((basePower + pitchShift + rollShift), -127, 127));
    motorPowerTR = int8_t(constrain((basePower + pitchShift - rollShift), -127, 127));
    motorPowerBR = int8_t(constrain((basePower - pitchShift - rollShift), -127, 127));
    motorPowerBL = int8_t(constrain((basePower - pitchShift + rollShift), -127, 127));
}

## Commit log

2024-11-02 PID-Controller: x-axis and vertical movement
2024-11-03 pitch and roll PID-controller. Constants can be tweeked for it to function better
2024-11-06 Motor controller
2024-11-08 motor calculation + output
2024-11-28 web: connect device
2025-01-08 switch to using start- and end-markers for messages
2025-01-12 test data reading using: wokwi - arduino uno
2025-01-13 base layout and power slider
2025-01-13 Show power and joystick values
2025-01-13 write pid constants
2025-01-16 read pid instructions
2025-01-16 change power display value to percentage
2025-01-16 Move MotorControl to utils
2025-01-20 Simulation: create motor power calculation function
2025-01-20 pitch and roll from gyroscope but slow
2025-01-21 better pitch and roll tracking
2025-01-21 Simulation - use calculated motor power
2025-01-22 Improve drone structure and fix errors
    [Drone.ino, RadioData.h]
2025-01-25 remove button_input from controller
2025-01-26 Add calculation of vertical velocity to Orientation
2025-01-26 Add all current radio message cases to Drone
2025-01-27 Remove test
    [Lock v1.3mf, armv3.3mf, kropp.3mf]
2025-01-27 Add message case prints
2025-01-27 fix PID referencing
2025-01-28 Fix motor power calculation
    [Drone.ino, MotorControl.cpp]
2025-01-28 Fix simulation angle and power calculations
2025-01-29 Fix IMU-reading
2025-01-29 Add yaw calculation (inaccurate)
2025-01-29 Update acceleration rotation matrix to include yaw-angle
2025-01-29 change simulation folder name from 'drone-simulation' to 'Simulation'
    [Lock v1.3mf, armv3.3mf, kropp.3mf]
2025-02-02 Fix receiver message handeling
    [Receiver.ino]
2025-02-26 Two way communication working. Received values from IMU are not accurate
2025-02-27 Correct IMU readings
2025-02-27 Scale accelerometer readings by g
2025-02-27 Fix HTML formatting for angular velocity and pitch/roll values
2025-02-27 Replace consoleLog with radioLog in Drone.ino
    [Drone.ino]
2025-03-02 Refactor MotorController to use PID_Instructions for setting velocity, pitch, and roll constants; streamline activation and deactivation processes; and enhance telemetry sequence handling.
2025-03-02 Remove unused button definitions from RadioData.h to clean up code
2025-03-04 Fix typos in SerializeField attributes and update pitch/roll calculations to use rigidbody rotation
2025-03-04 Add correct model to simulation
    [Lock.obj, arm.obj, vFINAL_kropp.obj]
2025-03-06 Add keyboard controls for power adjustment in drone simulation
2025-03-06 Smoth keyboard power-input
2025-03-10 Add CameraController to smoothly follow the drone's position
2025-03-14 Refactor telemetry sequence handling to use templated vector function and integrate SmoothValue for angles and velocity
2025-03-15 Fix motor power calculation and application
    [Drone.ino, MotorControl.cpp]
2025-03-16 Enhance button styling in CSS
2025-03-16 Add 'Write All' and 'Get All' buttons with functionality for PID and target range management
2025-03-16 Refactor PID and target range UI: enhance layout with grid styling and streamline button placement
2025-03-17 Refactor radio logging functions: replace radioLog with radioLogPush and add radioLogQueue for improved message handling
    [Drone.ino]
2025-03-17 Add motor power display and data handling in controller and drone code
2025-03-17 README: PID
2025-03-17 README: MotorController
2025-03-18 Update README: add Controller section and improve usage instructions for PID and MotorController classes
2025-03-19 Remove unused <SPI.h> header
2025-03-19 Update README: add note on using DroneLibrary with Arduino IDE
2025-03-19 Refactor controller and PID structures for clarity and consistency; update related documentation
2025-03-19 Update README: clarify flight data structure and units for acceleration, velocity, angular velocity, rotation, controller power, joystick, and fps
2025-03-21 Refactor flight data handling and improve code clarity; update angular velocity handling and clean up unused code
2025-03-31 Add Timer class
2025-03-31 Improve timed actions in 'Drone,ino' and 'Receiver.ino' by implementing Timer class
2025-04-01 Add timer class explaination to README.md
2025-04-03 Refactor timer implementation and update connection status handling
2025-04-23 Refactor sending logic and remove unused timer variables
2025-04-30 Refactor motor control to use Servo library for smoother operation
2025-05-10 Fix Orientation to account for IMU lever.
2025-05-12 Enhance communication handling by ignoring non-printable characters and improving connection status management
2025-05-12 Disable connection status due to unkown Serial error
    [Receiver.ino]
2025-05-12 Refactor Orientation class to include position offset and improve motor attachment logic; remove SmoothValue class
2025-05-12 Fix read function to continue on status checks and reorder write calls in loop for connection status
    [Receiver.ino]
2025-05-13 Calibrate drone
2025-05-14 Update README.md to include project materials
